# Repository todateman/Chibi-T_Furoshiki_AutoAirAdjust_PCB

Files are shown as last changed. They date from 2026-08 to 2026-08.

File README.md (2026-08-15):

# Chibi-T_Furoshiki_AutoAirAdjust_PCB

M5Stack Basic / Core2 用の空気圧自動調整コントローラー基板の KiCad プロジェクトです。  
1次側・2次側の空気圧センサと燃圧センサの値を M5Stack で監視し、ソレノイドバルブの開閉によって
1次側から2次側への圧縮空気の流れを自動制御します。

## 概要

- 対応ホスト: M5Stack Basic / Core2（MBUS 30pin コネクタで直結するスタック型基板）
- センサ入力
  - 1次側・2次側 空気圧センサ：[DFRobot Gravity MPX5700AP (SEN0456)](https://wiki.dfrobot.com/sen0456/docs/18937) × 2 個
    （センサ自体はアナログ出力のため、 I2C ADC モジュール経由で Grove I2C バスに接続）
  - 燃圧センサ：0–1.0 MPa / 0.5–4.5V アナログ出力タイプ 1 個
    （基板上の 12bit ADC（ADS1015）で読み取り）
- アクチュエータ出力：DC12Vソレノイドバルブ 1 系統（1次側→2次側の圧縮空気の開閉弁を GPIO トリガーで駆動）
- 電源：車両/バッテリーの 12V 入力から基板上の降圧コンバータで 5V を生成し、 M5Stack と各センサへ供給

## システム構成

```mermaid
flowchart TD
    J2["J2: from_12V_Power\n+12V入力"]
    F1["F1 ポリスイッチ\n(リセッタブルヒューズ)"]
    VBUS["VBUS\n保護後の12V系"]
    U1["U1 MP1584EN\n降圧DC/DCコンバータ\n12V → 5V"]
    V5["5V 系統"]
    J1["J1 M-BUS (30pin)\nM5Stack本体へ"]
    J3["J3 from_5V_Power\n外部5V供給/分岐用テストポイント"]
    J4["J4 PRESSURE_SEN\n燃圧センサ入力"]
    R10["R10 100kΩ\nAIN0 プルダウン\n(断線検出用)"]
    U2["U2 ADS1015\n12bit I2C ADC\nI2Cアドレス 0x48\nAIN0 = 燃圧センサ信号"]
    I2C["I2Cバス\nSDA/SCL\nM5Stack GPIO21/22"]
    J5["J5 Grove I2C\n外部I2C ADC経由\nGravity MPX5700AP #1\n(1次側空気圧センサ)"]
    J6["J6 Grove I2C\n外部I2C ADC経由\nGravity MPX5700AP #2\n(2次側空気圧センサ)"]
    Q1["Q1 AO3400A\nNchMOSFET\nローサイドスイッチ"]
    SOL_TRG["SOL_TRG\nM5Stack GPIO"]
    J7["J7 SOLENOID\nソレノイドバルブ(+)"]

    J2 --> F1 --> VBUS
    VBUS --> U1 --> V5
    VBUS --> J7
    VBUS --> Q1
    SOL_TRG -->|ゲート制御| Q1
    Q1 -->|スイッチング| GND

    V5 --> J1
    V5 --> J3
    V5 --> J4

    J4 --> U2
    R10 -.->|GND プルダウン| U2
    U2 --> I2C
    I2C --> J5
    I2C --> J6
```

## 主な機能

1. **空気圧計測（1次側・2次側）**
   Gravity MPX5700AP を 2 個、I2C ADC モジュール経由で Grove I2C コネクタ（J5・J6）に接続し、
   M5Stack の I2C バス上で読み取ります。  

   **2026.08.07 更新 Ver1.02**: M5Stack Basic / Core2 の I2C バスのピン配置は以下の通りです。

   | ボード | SDA | SCL |
   | --- | --- | --- |
   | M5Stack Basic | GPIO02 | GPIO05 |
   | M5Core2 | GPIO32 | GPIO33 |

   DFRobot Gravity MPX5700AP (SEN0456) のモジュール上の DIP スイッチで、I2Cアドレスは `0x16` 〜 `0x19` のいずれかに設定可能です。

2. **燃圧計測**
   0–1.0 MPa（0.5–4.5V 出力）のアナログ燃圧センサを J4（PRESSURE_SEN）に接続し、
   基板上の ADS1015（12bit I2C ADC、U2）の AIN0 チャンネルで読み取ります。  
   ADS1015 の ADDR ピンは GND に接続されており、I2C アドレスは `0x48` 固定です。

   **2026.08.15 更新 Ver1.03**: AIN0 ネット（J4 ピン2 ～ U2 AIN0 間）に R10（100kΩ、GNDプルダウン）を追加しました。  
   センサ本体は 0.5–4.5V 出力（0V付近には振れない）のため、J4 のセンサ配線が断線するとプルダウンにより AIN0 が 0V 付近まで下がり、ファームウェア側で「正常なセンサレンジ（≒0.5–4.5V相当のADC値）を下回っている＝断線」と判定できます。  
   R10 は 0603 サイズ・100kΩ（R2/R4 と同一部品、LCSC C25803）で、センサの低インピーダンス出力への影響はごく僅かです。  
   なお、ADS1015 の電源電圧は 3.3V（絶対最大定格 AIN ≦ VDD+0.3V ≒ 3.6V）である一方、センサ最大出力は 4.5V のため、現状の直結構成では正常動作範囲内でも ADC の絶対最大定格を超える可能性があります。  
   今回のプルダウン抵抗はこの問題を解決するものではなく、別途分圧抵抗などによるレベルシフトの検討が必要です。  
   （本リビジョンでは未対応）

3. **ソレノイドバルブ制御**
   1次側から2次側への圧縮空気の通路を開閉するソレノイドバルブを、M5Stack の GPIO（M5Stack: GPIO13 / Core2: GPIO19）, SOL_TRG）からのトリガー信号で駆動します。  
   GPIO → ゲート抵抗 R8(1kΩ) → Q1(AO3400A, NchMOSFET) のローサイドスイッチ構成で、R9(12kΩ) がゲートのプルダウン（起動時の誤動作防止）、D2(1N4148WS) が逆起電力吸収用フライホイールダイオードです。  
   **ソレノイドバルブの電源は VBUS（保護後の12V系統）から供給されます。**  
   **2026.07.14 更新 Ver1.01**: GPIO34は入力専用のため、ソレノイド駆動用のGPIOはGPIO13に変更しました。

4. **電源生成**
   J2（from_12V_Power）から入力した車両/バッテリー電源は、F1（ポリスイッチ／リセッタブルヒューズ）で保護された後、U1（MP1584EN-LF-Z 降圧 DC/DC コンバータ）で 5V に変換されます。  
   5V は J1（M-BUS）経由で M5Stack 本体、および J4 の燃圧センサ電源として供給されます。  
   3.3V 系統は M5Stack 本体（MBUS 経由）からの供給を利用しており、基板上では ADS1015 の電源および I2C プルアップ抵抗（R6, R7）に使われます。  
   J3（from_5V_Power）は外部への5V供給、または分岐出力を取り出すためのテストポイント/コネクタです。

## コネクタ一覧

| 番号 | 名称 | 種類 | 用途 |
| --- | --- | --- | --- |
| J1 | M-BUS | 2x15 (30pin) | M5Stack Basic/Core2 本体との直結用バスコネクタ |
| J2 | from_12V_Power | JST XH 1x02 | 車両/バッテリーからの 12V 電源入力 |
| J3 | from_5V_Power | Conn 1x02 | 外部 5V 供給／分岐出力用テストポイント |
| J4 | PRESSURE_SEN | JST XH 1x03 | 燃圧センサ入力（+5V／信号(AIN0)／GND、R10でGNDプルダウンし断線検出） |
| J5 | I2C | Grove 4pin | 外部I2C ADC経由で空気圧センサ(Gravity MPX5700AP)を接続 |
| J6 | I2C | Grove 4pin | 外部I2C ADC経由で空気圧センサ(Gravity MPX5700AP)を接続 |
| J7 | SOLENOID | JST XH 1x02 | ソレノイドバルブ駆動出力（VBUS系統をQ1でスイッチ） |

## 主要部品（抜粋）

| 部品番号 | 部品 | 役割 |
| --- | --- | --- |
| U1 | MP1584EN-LF-Z | 降圧DC/DCコンバータ（12V→5V、L1/R1/R3で出力電圧設定） |
| U2 | ADS1015IDGS | 12bit I2C ADC（燃圧センサ読み取り、I2Cアドレス 0x48） |
| Q1 | AO3400A | NchMOSFET（ソレノイドバルブのローサイドスイッチ） |
| D1 | Schottky | 電源保護用ダイオード |
| D2 | 1N4148WS | ソレノイドコイルのフライホイールダイオード |
| F1 | Polyfuse (Polyfuse_Small) | 12V入力のリセッタブルヒューズ |
| L1 | 10uH | 降圧コンバータのインダクタ |
| R10 | 100k (0603) | AIN0（J4燃圧センサ信号）のGNDプルダウン。センサ断線検出用 |

部品表全体は [`production/bom.csv`](production/bom.csv) を参照してください。

## 基板仕様

- 基板サイズ：約 50.05mm × 50.05mm x 1.0mm
- 層数：2層（F.Cu / B.Cu）
- マウントホール：M3 × 4（H1–H4）、M2 × 4（H5–H8）
- KiCad バージョン：KiCad 8 系フォーマット

## ディレクトリ構成

```txt
├── Chibi-T_Furoshiki_AutoAirAdjust_PCB.kicad_pro   # プロジェクトファイル
├── Chibi-T_Furoshiki_AutoAirAdjust_PCB.kicad_sch    # 回路図
├── Chibi-T_Furoshiki_AutoAirAdjust_PCB.kicad_pcb    # 基板データ
├── C15051/                                          # MP1584EN 用シンボルライブラリ
├── OPL_Connector.lib / OPL_Connector.pretty/         # コネクタ用シンボル・フットプリントライブラリ
├── logos.pretty/                                    # 基板ロゴ用フットプリント
├── production/                                       # 製造用出力データ（ガーバー一式・BOM・部品配置等）
├── Chibi-T_Furoshiki_AutoAirAdjust_PCB-backups/      # KiCad 自動バックアップ（zip）
└── LICENSE.txt                                       # ライセンス（MIT）
```

## 製造データ

`production/` フォルダに、製造発注用のデータ一式が出力済みです。

- `Chibi-T_Furoshiki_AutoAirAdjust_PCB.zip` … ガーバー等一式
- `bom.csv` … 部品表
- `positions.csv` … 部品実装位置データ（ピックアンドプレース）
- `designators.csv` … 部品番号リスト
- `netlist.ipc` … IPC ネットリスト

## ファームウェア

M5Stack 側の制御プログラム（センサ読み取り・ソレノイド制御ロジック）は本リポジトリには含まれません。
別リポジトリで管理しています。

## ライセンス

MIT License（詳細は [`LICENSE.txt`](LICENSE.txt) を参照）

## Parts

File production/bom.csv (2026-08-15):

Designator | Footprint | Quantity | Value | LCSC Part #
C1 | 1206 | 1 | 100uF | C15008
C2, C3, C4 | 0603 | 3 | 22uF | C59461
C5 | 0603 | 1 | 150pF | C1594
C6, C7 | 0805 | 2 | 2.2uF | C377773
C8 | 0402 | 1 | 0.1uF | C1525
D1 | D_SMA | 1 | D_Schottky | C22452
D2 | D_SOD-323 | 1 | 1N4148WS | C2128
F1 | 1812 | 1 | Polyfuse_Small | C1884489
H1, H2, H3, H4 | BF@MountingHole_3.2mm_M3 | 4 | MountingHole
H5, H6, H7, H8 | BF@MountingHole_2.2mm_M2 | 4 | MountingHole
J1 | BF@M5Stack_MBUS | 1 | M-BUS
J2 | JST_XH_S2B-XH-A_1x02_P2.50mm_Horizontal | 1 | from_12V_Power
J4 | JST_XH_S3B-XH-A_1x03_P2.50mm_Horizontal | 1 | PRESSURE_SEN
J6 | GROVE-HW4-2.0-90D | 1 | I2C
J7 | JST_XH_S2B-XH-A_1x02_P2.50mm_Horizontal | 1 | SOLENOID
L1 | L_Sunlord_SWPA3015S | 1 | 10uH | C45403
Q1 | SOT-23 | 1 | AO3400A | C20917
R1 | 0603 | 1 | 52.3k | C23198
R10, R2, R4 | 0603 | 3 | 100k | C25803
R3, R5, R6, R7 | 0805 | 4 | 10k | C17414
R8 | 0805 | 1 | 1k | C17513
R9 | 0805 | 1 | 12k | C17444
U1 | SOIC-8_L5.0-W4.0-P1.27-LS6.0-BL-EP2.0 | 1 | MP1584EN-LF-Z | C15051
U2 | TSSOP-10_3x3mm_P0.5mm | 1 | ADS1015IDGS | C193969

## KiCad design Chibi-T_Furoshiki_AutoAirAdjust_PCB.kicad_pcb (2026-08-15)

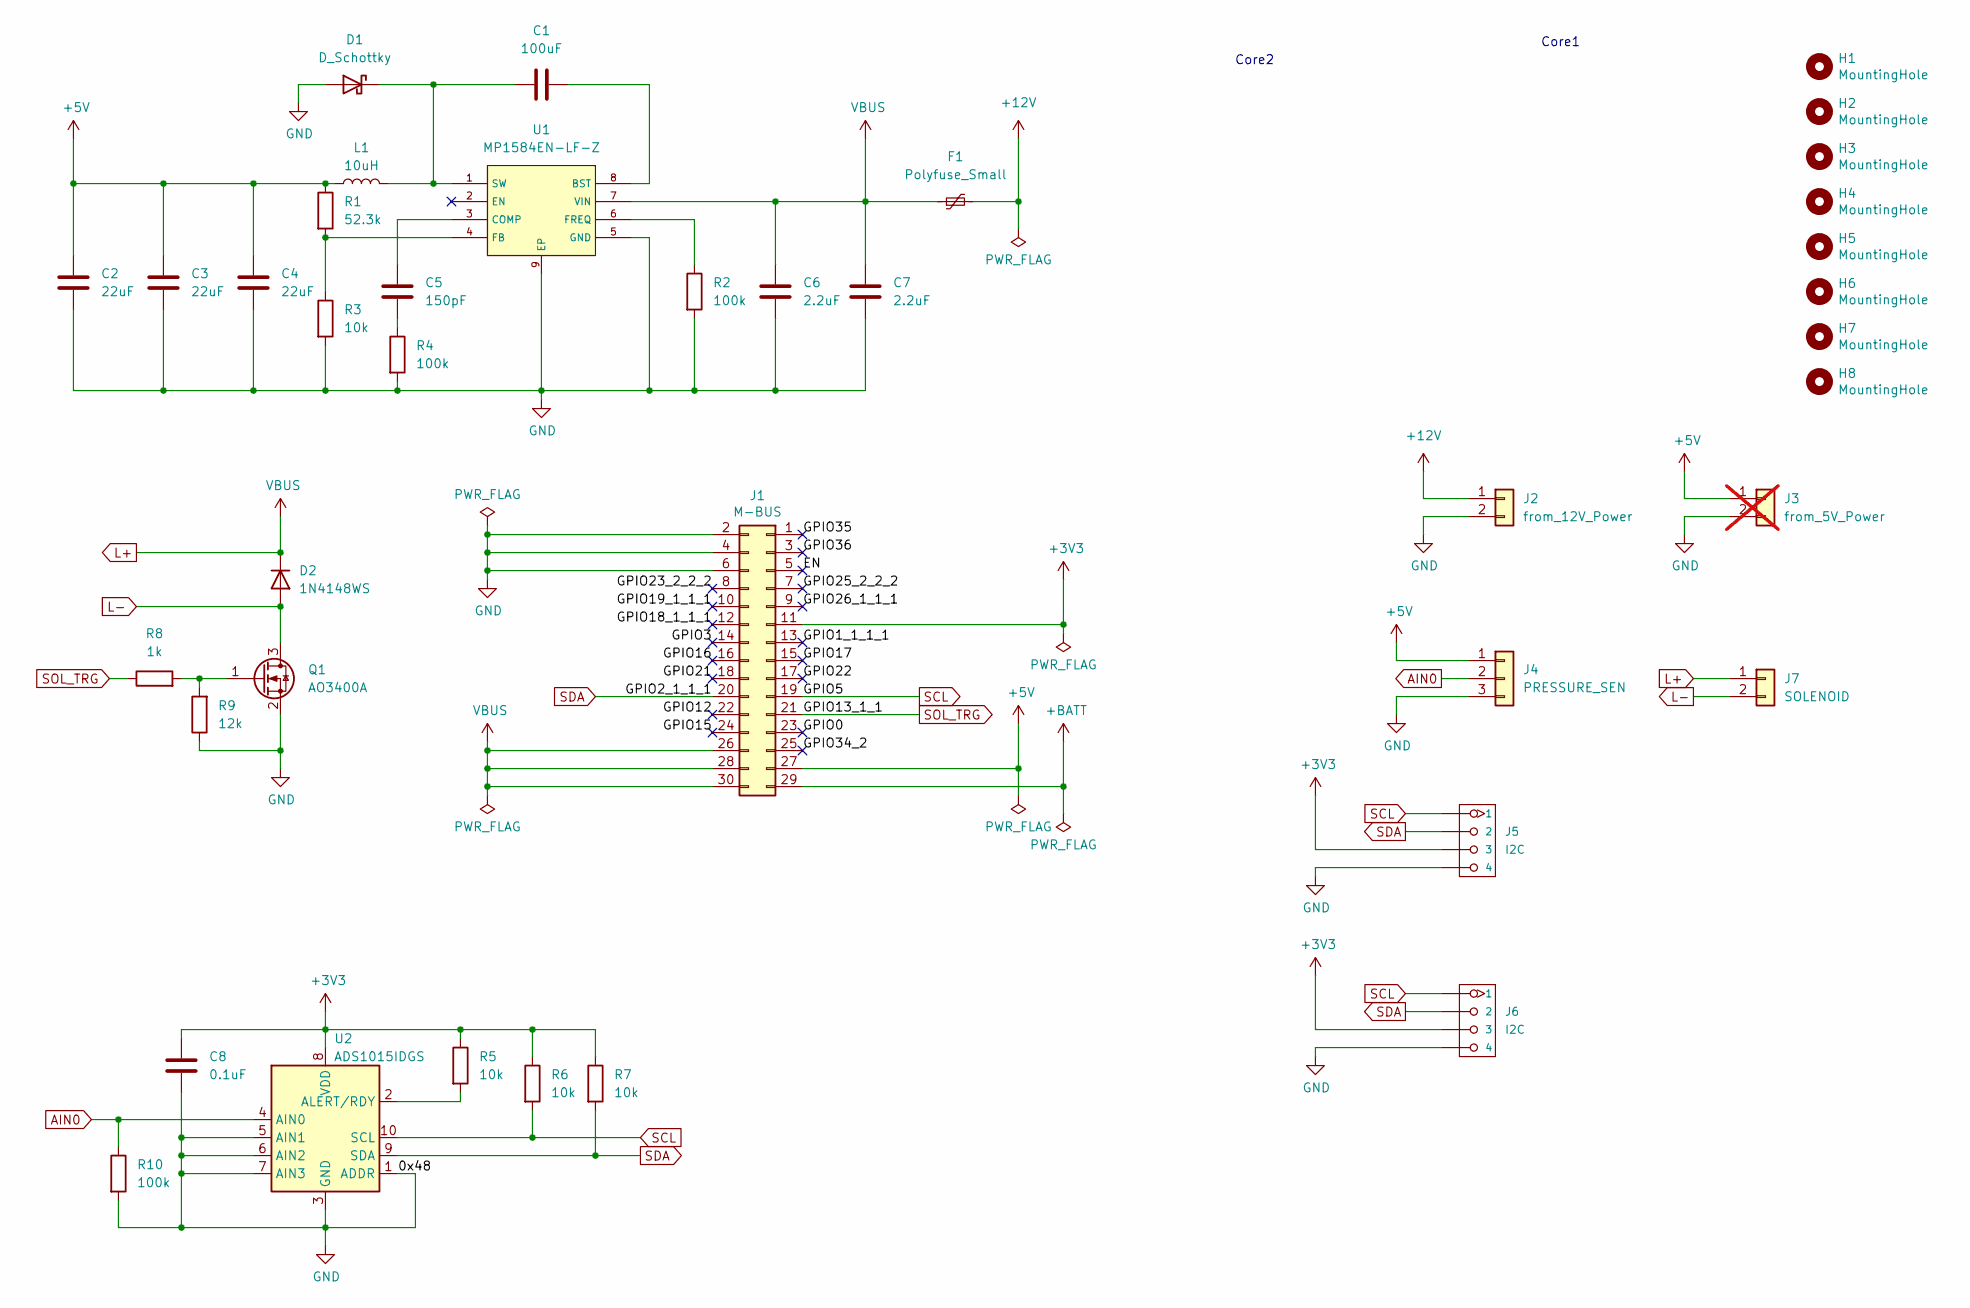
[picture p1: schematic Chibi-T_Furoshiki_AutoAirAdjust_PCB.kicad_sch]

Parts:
C1: 100uF; C_1206_3216Metric; LCSC C15008
C2, C3, C4: 22uF; C_0603_1608Metric; LCSC C59461
C5: 150pF; C_0603_1608Metric; LCSC C1594
C6, C7: 2.2uF; C_0805_2012Metric; LCSC C377773
C8: 0.1uF; C_0402_1005Metric; LCSC C1525
D1: D_Schottky; D_SMA; LCSC C22452
D2: 1N4148WS; D_SOD-323; LCSC C2128
F1: Polyfuse_Small; Fuse_1812_4532Metric; LCSC C1884489
H1, H2, H3, H4: MountingHole; BF@MountingHole_3.2mm_M3
H5, H6, H7, H8: MountingHole; BF@MountingHole_2.2mm_M2
J1: M-BUS; BF@M5Stack_MBUS
J2: from_12V_Power; JST_XH_S2B-XH-A_1x02_P2.50mm_Horizontal
J3: from_5V_Power; PinSocket_1x02_P2.54mm_Vertical; not fitted
J4: PRESSURE_SEN; JST_XH_S3B-XH-A_1x03_P2.50mm_Horizontal
J5, J6: I2C; GROVE-HW4-2.0-90D
J7: SOLENOID; JST_XH_S2B-XH-A_1x02_P2.50mm_Horizontal
L1: 10uH; L_Sunlord_SWPA3015S; LCSC C45403
Q1: AO3400A; SOT-23; LCSC C20917
R1: 52.3k; R_0603_1608Metric; LCSC C23198
R2, R4, R10: 100k; R_0603_1608Metric; LCSC C25803
R3, R5, R6, R7: 10k; R_0805_2012Metric; LCSC C17414
R8: 1k; R_0805_2012Metric; LCSC C17513
R9: 12k; R_0805_2012Metric; LCSC C17444
U1: MP1584EN-LF-Z; SOIC-8_L5.0-W4.0-P1.27-LS6.0-BL-EP2.0; Manufacturer Part MP1584EN-LF-Z; LCSC C15051
U2: ADS1015IDGS; TSSOP-10_3x3mm_P0.5mm; LCSC C193969

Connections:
/EN: J1.5
/EN_1: J1.5
/EN_2: J1.5
/GPIO0: J1.23
/GPIO0_1: J1.23
/GPIO0_2: J1.23
/GPIO1_1_1_1: J1.13
/GPIO1_1_1_1_1: J1.13
/GPIO1_1_1_1_2: J1.13
/GPIO3: J1.14
/GPIO3_1: J1.14
/GPIO3_2: J1.14
/GPIO12: J1.22
/GPIO12_1: J1.22
/GPIO12_2: J1.22
/GPIO15: J1.24
/GPIO15_1: J1.24
/GPIO15_2: J1.24
/GPIO16: J1.16
/GPIO16_1: J1.16
/GPIO16_2: J1.16
/GPIO17: J1.15
/GPIO17_1: J1.15
/GPIO17_2: J1.15
/GPIO18_1_1_1: J1.12
/GPIO18_1_1_1_1: J1.12
/GPIO18_1_1_1_2: J1.12
/GPIO19_1_1_1: J1.10
/GPIO19_1_1_1_1: J1.10
/GPIO19_1_1_1_2: J1.10
/GPIO21: J1.18
/GPIO21_1: J1.18
/GPIO21_2: J1.18
/GPIO22: J1.17
/GPIO22_1: J1.17
/GPIO22_2: J1.17
/GPIO23_2_2_2: J1.8
/GPIO23_2_2_2_1: J1.8
/GPIO23_2_2_2_2: J1.8
/GPIO25_2_2_2: J1.7
/GPIO25_2_2_2_1: J1.7
/GPIO25_2_2_2_2: J1.7
/GPIO26_1_1_1: J1.9
/GPIO26_1_1_1_1: J1.9
/GPIO26_1_1_1_2: J1.9
/GPIO34_2: J1.25
/GPIO34_2_1: J1.25
/GPIO34_2_2: J1.25
/GPIO35: J1.1
/GPIO35_1: J1.1
/GPIO35_2: J1.1
/GPIO36: J1.3
/GPIO36_1: J1.3
/GPIO36_2: J1.3
AIN0: J4.2, R10.1, U2.4 (AIN0)
L-: D2.2 (A), J7.2, Q1.3 (D)
unnamed: C5.1, R4.1
unnamed: C1.1, D1.1 (K), L1.2, U1.1 (SW)
unnamed: Q1.1 (G), R8.2, R9.2
unnamed: C1.2, U1.8 (BST)
unnamed: C5.2, U1.3 (COMP)
unnamed: R1.2, R3.1, U1.4 (FB)
unnamed: R2.1, U1.6 (FREQ)
unnamed: R5.2, U2.2 (ALERT/RDY)
SCL: J1.19, J5.1, J6.1, R6.2, U2.10 (SCL)
SDA: J1.20, J5.2, J6.2, R7.2, U2.9 (SDA)
SOL_TRG: J1.21, R8.1

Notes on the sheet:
Core1
Core2

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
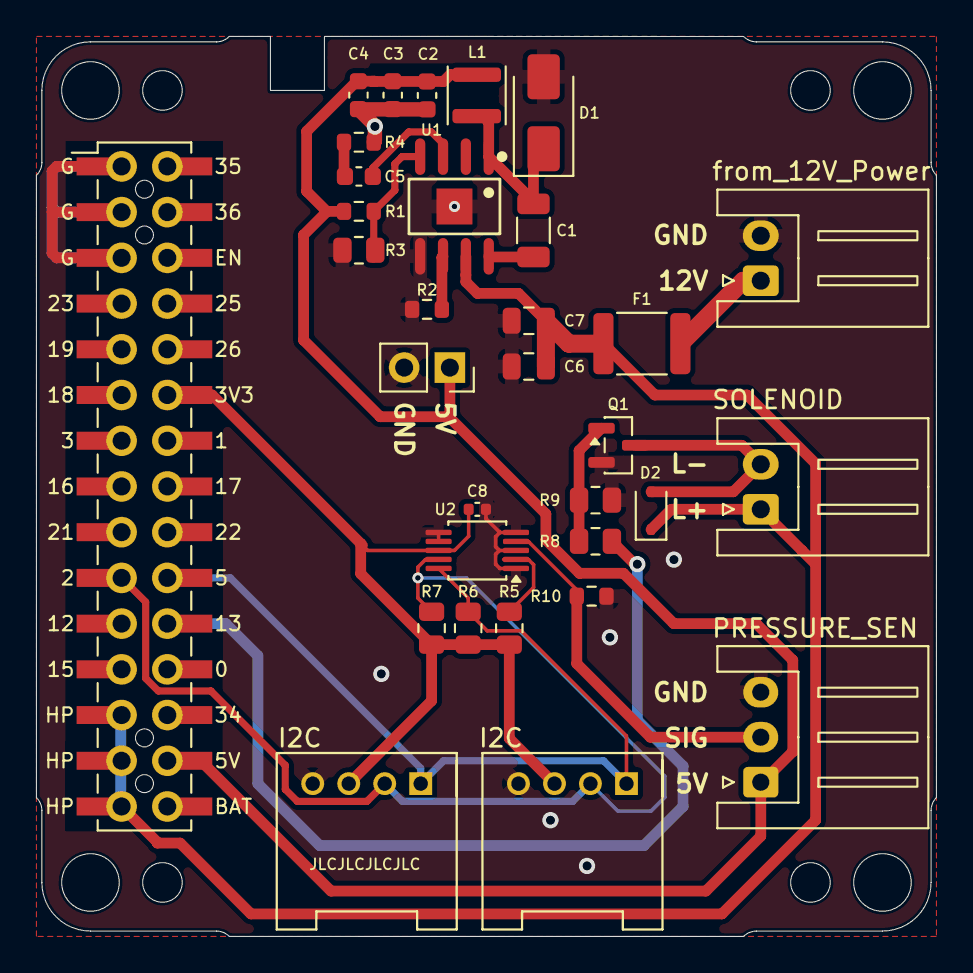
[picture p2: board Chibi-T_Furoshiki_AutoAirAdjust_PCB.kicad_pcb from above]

Board: 2 copper layers, 50.0 x 50.0 mm, 40 parts (0 on the bottom side), 18 nets.

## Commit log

2026-07-12 feature: 新しいPCBデザインと部品表を追加
    [Chibi-T_Furoshiki_AutoAirAdjust_PCB.kicad_pcb, Chibi-T_Furoshiki_AutoAirAdjust_PCB.kicad_sch, bom.csv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]
2026-07-13 docs: ソレノイドバルブ制御のGPIOを34から13に変更。Ver.1.00→1.01
    [Chibi-T_Furoshiki_AutoAirAdjust_PCB.kicad_pcb, Chibi-T_Furoshiki_AutoAirAdjust_PCB.kicad_sch]
2026-08-07 faeyure: I2CバスのGPIOピンを変更
    [Chibi-T_Furoshiki_AutoAirAdjust_PCB.kicad_pcb, Chibi-T_Furoshiki_AutoAirAdjust_PCB.kicad_sch]
2026-08-15 feature: 燃圧センサの断線検知用プルダウン抵抗を追加
    [Chibi-T_Furoshiki_AutoAirAdjust_PCB.kicad_pcb, Chibi-T_Furoshiki_AutoAirAdjust_PCB.kicad_sch, bom.csv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]
